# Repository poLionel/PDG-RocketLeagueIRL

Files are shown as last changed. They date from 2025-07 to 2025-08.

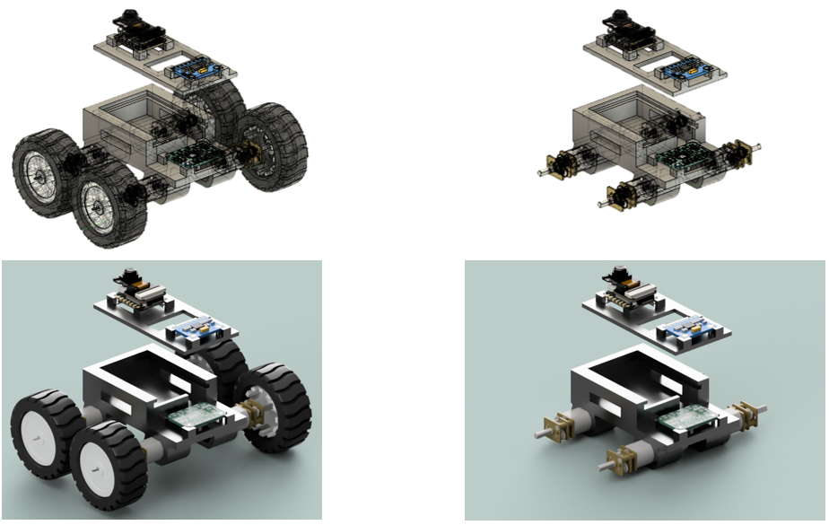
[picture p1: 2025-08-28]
cars/hardware/3d/all_perspectives.png

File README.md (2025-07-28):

# PDG-RocketLeagueIRL

https://polionel.github.io/PDG-RocketLeagueIRL/

Demonstration

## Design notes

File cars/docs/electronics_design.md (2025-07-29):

# Design

Ce document décrit les choix techniques et la justification des composants sélectionnés pour la conception des voitures.  
Le composant central est l’**ESP32-S3 avec caméra intégrée**, qui assure à la fois la gestion des capteurs, la communication et le contrôle moteur.

---

## 1. Composant central : ESP32-S3 + Caméra intégrée
- **Rôle :**  
  - Microcontrôleur principal du véhicule  
  - Gestion des entrées/sorties (moteurs, capteurs)  
  - Traitement de la vidéo embarquée pour détection et streaming
  - Communication avec le serveur (Wi-Fi et Bluetooth)
- **Justification :**  
  - Intègre Wi-Fi et Bluetooth (pas besoin de module externe)  
  - Supporte traitement d'image embarqué (via capteur OV2640)  
  - Gestion de charge batterie Li-Po 3,7 V
- **Référence choisie :** Seeed Studio XIAO ESP32-S3 Sense  
  - Compact, facile à intégrer dans un châssis  
  - Caméra intégrée 
  - Prix compétitif

---

## 2. Moteurs DC
- **Rôle :**  
  - Fournir la propulsion et le contrôle directionnel
- **Justification :**  
  - Simplicité de commande via driver H-bridge  
  - Tension compatible avec la batterie Li-Po 3,7 V  
  - Disponibilité en lots à faible coût
- **Référence :** JYD061217 – JIE YI ELECTRONICS  
  - Couple suffisant pour la taille et le poids prévus du véhicule

---

## 3. Driver moteur DC double canal (Adafruit DRV8833)
- **Rôle :**  
  - Piloter deux moteurs DC en contrôle bidirectionnel  
- **Justification :**  
  - Double pont en H, support jusqu’à 1,2 A par moteur  
  - Compatible avec les tensions des moteurs et l’ESP32  
  - Facilement disponible (Adafruit, Digitec)
- **Avantage :**  
  - Commande simple via GPIO de l’ESP32  
  - Compact et efficace

---

## 4. Accéléromètre 3 axes (MPU-6050)
- **Rôle :**  
  - Mesurer l’orientation, l’inclinaison et les chocs  
  - Améliorer le contrôle dynamique du véhicule
- **Justification :**  
  - Très utilisé dans les projets robotiques  
  - Communication I2C facile à intégrer avec l’ESP32  
  - Faible consommation
- **Référence :** Purecrea MPU-6050

---

## 5. Batterie Li-Po
- **Rôle :**  
  Alimenter l’ensemble du système embarqué : microcontrôleur, moteurs et capteurs.

- **Caractéristiques de la batterie sélectionnée :**  
  - Type : Li-Po  
  - Tension : 3.7 V  
  - Capacité : 1000 mAh  

### Consommation maximale estimée :
| Composant | Courant estimé |
|---|---|
| ESP32-S3 + caméra OV2640 | ~330 mA |
| 4 moteurs DC (50 mA chacun) | ~200 mA |
| Driver moteur DRV8833 (pertes internes) | ~20 mA |
| Accéléromètre 3 axes (MPU-6050 avec DMP) | ~6 mA |
| **Total** | **≈ 556 mA** |

### Calcul autonomie batterie :
Formule :  
**Capacité (mAh) = Courant (mA) × Durée (h)**

- Pour 30 minutes (0.5 h) :  
  `556 mA × 0.5 h = 278 mAh`
- Pour 1 heure :  
  `556 mA × 1 h = 556 mAh`

#### 🔒 Marge de sécurité 30 % incluse :
- 30 min → `278 mAh × 1.3 = 361.4 mAh`
- 1 h → `556 mAh × 1.3 = 722.8 mAh`

### Conclusion :
Avec une batterie de **1000 mAh**, le système peut fonctionner :
- Environ **1h30** en utilisation soutenue
- Avec **30 % de marge**, il couvre confortablement **jusqu'à 1h en pleine charge continue**

---

## 📌 Conclusion
L’architecture repose sur un ESP32-S3 centralisé, relié directement aux moteurs via driver, et aux capteurs via bus I2C.  
Ce choix maximise la compacité, la performance et la facilité de développement tout en restant économique.

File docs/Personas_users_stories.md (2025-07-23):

# Personas

## Joueur qui connaît Rocket League

**Description :**
Passionné du jeu vidéo Rocket League, il connaît déjà les mécaniques, les règles et les stratégies du jeu virtuel. Il recherche une expérience fidèle et compétitive dans le monde réel.

**Buts :**
- Retrouver les sensations et la dynamique du jeu vidéo.
- Tester ses compétences dans un contexte physique.
- S’amuser et relever des défis contre d’autres joueurs expérimentés.

## Joueur qui ne connaît pas Rocket League

**Description :**
Découvre le concept Rocket League pour la première fois. Il aime les jeux ou les activités ludiques, mais n’a pas d’expérience préalable avec le jeu vidéo.

**Buts :**
- Comprendre rapidement les règles et la prise en main.
- S’amuser sans être désavantagé par son manque d’expérience.
- Profiter d’une expérience accessible et intuitive.

## Arbitre

**Description :**
Personne responsable du bon déroulement des matchs, du respect des règles et de la validation des scores. Il peut être membre de l’organisation ou un joueur désigné.

**Buts :**
- Garantir l’équité et la sécurité pendant les parties.
- Gérer les litiges et valider les événements de jeu (buts, fautes).
- Disposer d’outils simples pour surveiller et contrôler la partie.

## Spectateur

**Description :**
Individu qui assiste aux matchs sans y participer directement. Il peut être un proche des joueurs, un fan ou un curieux.

**Buts :**
- Suivre l’action en direct de façon immersive.
- Comprendre facilement le score et les événements du match.
- Profiter d’une expérience divertissante, éventuellement via une application ou un écran.

## Développeur ou contributeur externe

**Description :**
Personne souhaitant contribuer au projet (ajout de fonctionnalités, correction de bugs, documentation). Peut être membre de l’équipe ou externe.

**Buts :**
- Comprendre rapidement l’architecture et les conventions du projet.
- Pouvoir tester et déployer facilement ses modifications.
- Participer à une communauté ouverte et bien documentée.

# User Stories

## Joueur qui connaît Rocket League

- En tant que joueur expérimenté, je veux retrouver les mêmes sensations de contrôle qu’en jeu vidéo pour m’adapter rapidement.
- En tant que joueur expérimenté, je veux pouvoir utiliser des stratégies avancées pour prendre l’avantage sur mes adversaires.
- En tant que joueur expérimenté, je veux que le système gère les collisions.
- En tant que joueur expérimenté, je veux que le système gère les boosts.
- En tant que joueur expérimenté, je veux accéder à des statistiques détaillées de mes parties pour analyser mes performances.
- En tant que joueur expérimenté, je veux pouvoir personnaliser les contrôles de l’application mobile selon mes préférences.

## Joueur qui ne connaît pas Rocket League

- En tant que nouveau joueur, je veux un tutoriel simple pour comprendre rapidement les règles du jeu.
- En tant que nouveau joueur, je veux que l’interface soit intuitive afin de prendre en main la voiture sans difficulté.
- En tant que nouveau joueur, je veux pouvoir jouer sans être désavantagé face à des joueurs expérimentés.
- En tant que nouveau joueur, je veux pouvoir rejoindre une partie facilement.

## Arbitre

- En tant qu’arbitre, je veux pouvoir valider ou annuler un but depuis une interface dédiée.
- En tant qu’arbitre, je veux pouvoir mettre en pause ou arrêter la partie à tout moment.
- En tant qu’arbitre, je veux accéder à un historique des événements pour résoudre les litiges.
- En tant qu’arbitre, je veux pouvoir modifier le score manuellement si nécessaire.

## Spectateur

- En tant que spectateur, je veux suivre le match en direct via un flux vidéo pour ne rien manquer de l’action.
- En tant que spectateur, je veux voir le score et le temps restant affichés clairement.
- En tant que spectateur, je veux pouvoir choisir la vue de la voiture.
- En tant que spectateur, je veux recevoir des notifications lors des moments clés (buts, boosts, collisions).

## Développeur ou contributeur externe

- En tant que développeur, je veux accéder à une documentation claire pour comprendre rapidement le projet.
- En tant que développeur, je veux pouvoir lancer un environnement de test local.
- En tant que développeur, je veux que le code soit bien structuré et commenté pour faciliter mes contributions.
- En tant que développeur, je veux soumettre des modifications via des pull requests et recevoir des retours.
- En tant que développeur, je veux que les tests automatisés valident mes changements avant intégration.

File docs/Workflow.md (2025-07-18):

 # 1. Architecture du repo

```arduino
rocket-league-physique/
├── server/        # ???
├── cars/          # ???
├── mobile/        # appli .NET MAUI
├── infra/         # docker-compose, scripts Ansible/Terraform
└── docs/          # schémas, spécs, README, wiki…
```

# 2. Système de branches (Git-flow)

develop

    - Branche d’intégration continue.
    - On y merge toutes les feature/* et bugfix/*.

feature/xxx & bugfix/yyy

    - Branches filles de develop (git checkout -b feature/123-nouvelle-cam).
    - PR → merge → CI runs.

release/vX.Y.Z

    - Créée depuis develop quand on est prêt pour une version.
    - Stabilisation (QA, tests E2E) sans intégrer de nouvelles features.
    - Puis merge → main + tag vX.Y.Z → déploiement.
    - Merge aussi vers develop pour récupérer correctifs.

main

    - Branche de production, jamais de merges directs de features.
    - Chaque tag vX.Y.Z sur main déclenche le CD.

hotfix/vX.Y.Z

    - Branche crée depuis main pour corriger urgemment un bug.
    - Corrections en branches filles (hotfix/vX.Y.Z-fix…) → PR → merge dans hotfix/vX.Y.Z.
    - Merge → main + tag → déploiement immédiat.
    - Merge → develop pour propager la correction.

# 3. Tags Git & Releases
- Format sémantique : vMAJEUR.MINOR.PATCH (ex. v1.0.0, v1.2.2)
- Création anotée :

```bash
git tag -a v1.1.2 -m "Hotfix v1.1.2 - Crash x fix"
git push origin v.1.1.2
```

- Usage
    - Reste figé sur le commit de release
    - Déclencheur CD (dans cd.yaml)

- Github Releases : associez notes de version et artefacts (Docker, firmware,...)

# 4. Pipelines Github Actions
## 1) .github/workflows/ci.yaml
    - Déchencheurs : push & pull_request sur develop, feature/*, bugfix/*
    - Jobs (parallèles) :
        - Test AppMobile (dotnet test)
        - Test Server
        - Test Firmware
    - Objectif : feedback rapide, qualité du code

## 2) .github/workflows/e2e.yaml (todo : à voir si besoin)

## 3) .github/workflows/cd.yaml
    - Déclencheur : push de tags v*.*.*
    - Job :
        - A voir mais build & push docker images, générer binaire, ...

# 5. Outils & environnements
    - Issue tracker : Github Issues + Project (kanban), templates, labels(bug, feature, etc)
    - Docs : dossier docs/
    - autres ?

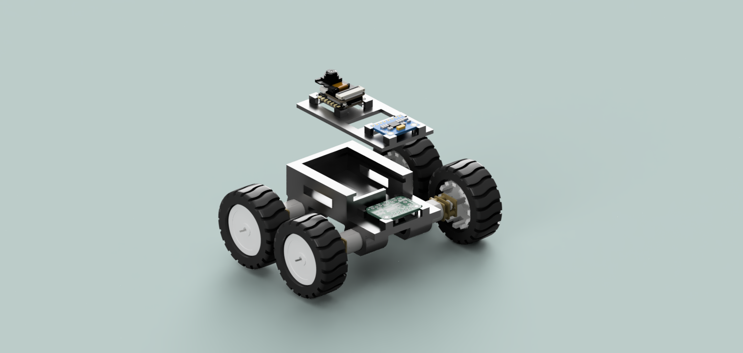
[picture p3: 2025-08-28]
cars/hardware/3d/car_full_with_wheels.PNG

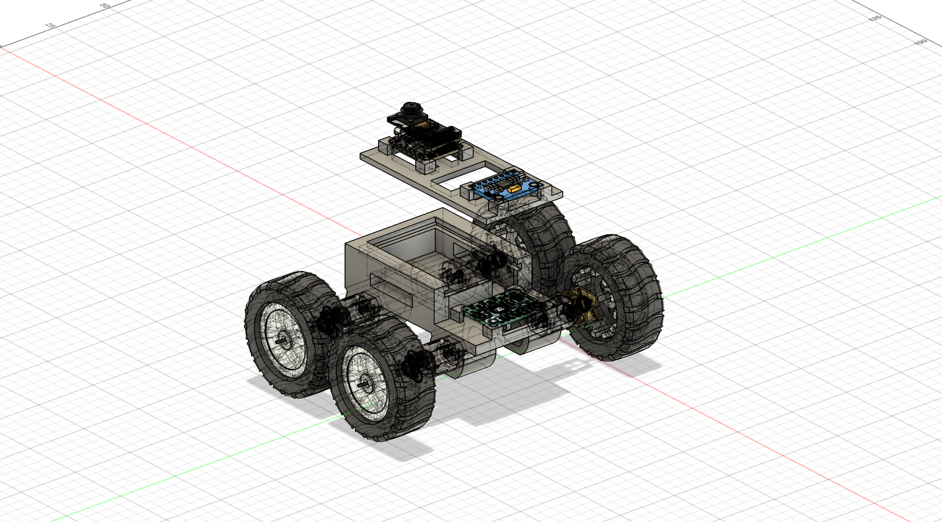
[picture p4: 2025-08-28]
cars/hardware/3d/car_chassis_v3.png

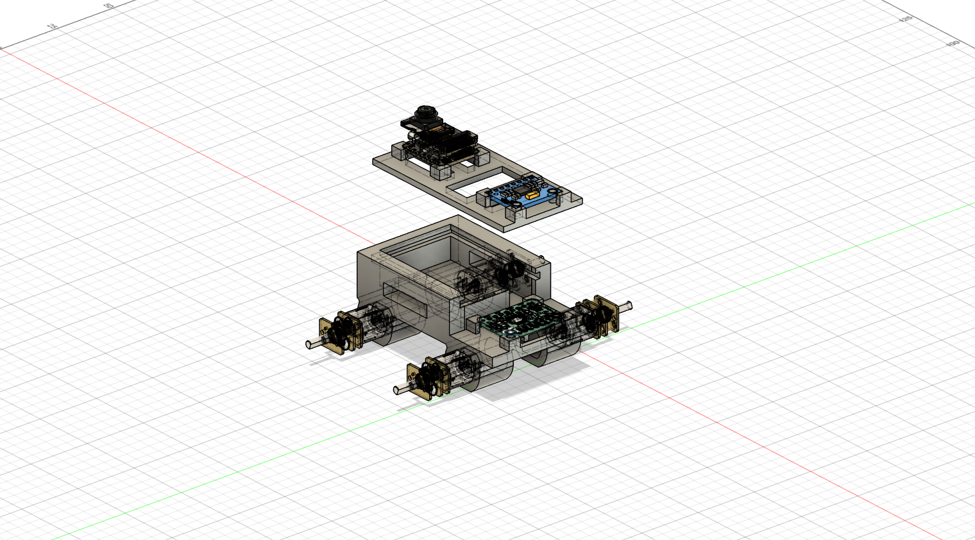
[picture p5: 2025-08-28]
cars/hardware/3d/car_chassis_v4.png

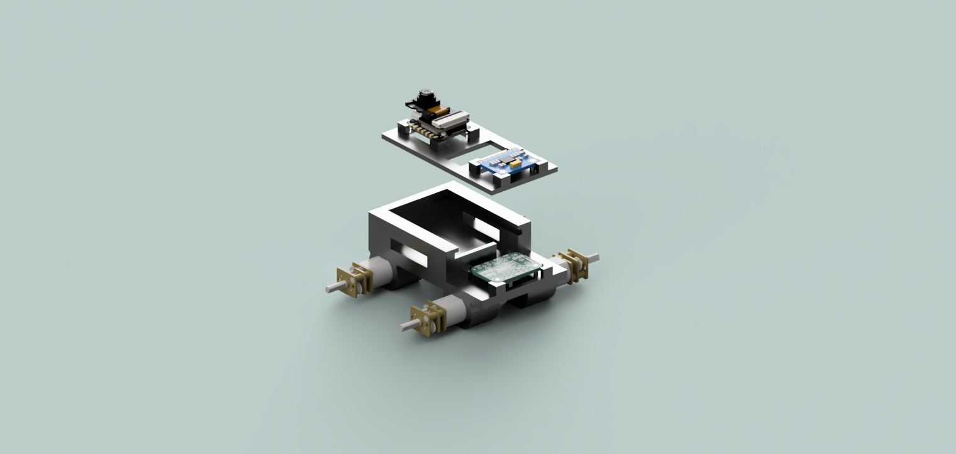
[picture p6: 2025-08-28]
cars/hardware/3d/car_full_without_wheels.png

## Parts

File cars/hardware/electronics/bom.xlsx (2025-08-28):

Composant | Quantité | Caractéristiques | Nom Fournisseur | Référence Fournisseur | Prix unitaire | Total
Moteur GA12-N20 DC 3V | 4 | Tension nominale : 3V Courant nominale : 70mA Couple nomiale : 2kg*cm Vitesse à vide : 100 RPM | Digikey | https://www.amazon.fr/-/en/gp/product/B0CJY5QH7W?ref=ppx_pt2_dt_b_prod_image&th=1 | 1.88 | 7.52
Module ESP32 + caméra intégré | 1 | Type Processeur : ESP32-S3 Capteur intégré : OV2640 Batterie : compatible 3.7V Li‑Ion Wi-Fi : Wi‑Fi 802.11 b/g/n Bluetooth : 5 (BLE) Consommation maximale: (CPU+WiFi+BLE)~240mA + (Cam.OV2640)~60mA + (ChargeurLiPo)~20-30mA =230-330mA | Digitec | Seeed Studio XIAO ESP32 S3 Sense avec caméra - acheter sur Digitec (https://www.digitec.ch/fr/s1/product/seeed-studio-xiao-esp32-s3-sense-avec-camera-carte-de-developpement-kit-35506126) | 30.9 | 30.9
Module driver moteur DC double canal Adafruit DRV8833 | 1 | Type : Double pont en H Tension moteur : 2.7 V à 10.8 V Courant max : 1.2 A continu Entrée logique : 3.3 V / 5 V Contrôle : PWM, sens, ... Nombre de canaux : 2 consommation : 20mA (pertes) | Digitec | Adafruit DRV8833 Tableau d'affichage pour les conducteurs de moteurs pas à pas - Digitec (https://www.digitec.ch/fr/s1/product/adafruit-drv8833-tableau-daffichage-pour-les-conducteurs-de-moteurs-pas-a-pas-diode-5998725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) | 12.9 | 12.9
Module accelérometre 3 axes Purecrea MPU-6050 | 1 | Alimentation : 3,3 V à 5 V Communication : I2C Mesure : ± 2 g, ± 4 g, ± 8 g, ± 16 g Consommation : 5,5 mA | Digitec | Purecrea MPU-6050 3-axis accelerometer with gyroscope - buy at Digitec (https://www.digitec.ch/en/s1/product/purecrea-mpu-6050-3-axis-accelerometer-with-gyroscope-development-boards-kits-36359715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) | 12.9 | 12.9
Batterie | 1 | Li-Po 3.7 V 1000 mAh | Digitec | Akyga LP803040 Akkupack x Spezial-Akku LiPo 3.7 V 1000 mAh - Digitec (https://www.digitec.ch/fr/s1/product/akyga-lp803040-akkupack-x-spezial-akku-lipo-37-v-1000-mah-370-v-1000-mah-batterie-rc-56400957) | 7.9 | 7.9
 |  |  |  |  | Total | 72.12

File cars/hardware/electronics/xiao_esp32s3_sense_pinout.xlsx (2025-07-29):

Name | No. | Type | Power Domain | Function
LNA_IN | 1 | I/O | — | RF input and output
VDD3P3 | 2 | PA | — | Analog Power
VDD3P3 | 3 | PA | — | Analog Power
CHIP_PU | 4 | I | VDD3P3_RTC | High level: chip enable; Low: chip off; Note that the CHIP_PU pin cannot be left floating.
GPIO0 | 5 | I/O/T | VDD3P3_RTC | RTC_GPIO0 | GPIO0 |  |  |  |  |  | BOOT
GPIO1 | 6 | I/O/T | VDD3P3_RTC | RTC_GPIO1 | GPIO1 | TOUCH1 | ADC1_CH0 |  |  |  | D0 | A0 | GPIO1 | TOUCH1
GPIO2 | 7 | I/O/T | VDD3P3_RTC | RTC_GPIO2 | GPIO2 | TOUCH2 | ADC1_CH1 |  |  |  | D1 | A1 | GPIO2 | TOUCH2
GPIO3 | 8 | I/O/T | VDD3P3_RTC | RTC_GPIO3 | GPIO3 | TOUCH3 | ADC1_CH2 |  |  |  | D2 | A2 | GPIO3 | TOUCH3
GPIO4 | 9 | I/O/T | VDD3P3_RTC | RTC_GPIO4 | GPIO4 | TOUCH4 | ADC1_CH3 |  |  |  | D3 | A3 | GPIO4 | TOUCH4
GPIO5 | 10 | I/O/T | VDD3P3_RTC | RTC_GPIO5 | GPIO5 | TOUCH5 | ADC1_CH4 |  |  |  | D4 | A4 | GPIO5 | TOUCH5 | SDA
GPIO6 | 11 | I/O/T | VDD3P3_RTC | RTC_GPIO6 | GPIO6 | TOUCH6 | ADC1_CH5 |  |  |  | D5 | A5 | GPIO6 | TOUCH6 | SCL
GPIO7 | 12 | I/O/T | VDD3P3_RTC | RTC_GPIO7 | GPIO7 | TOUCH7 | ADC1_CH6 |  |  |  | D8 | A8 | GPIO7 | TOUCH7 | SCK
GPIO8 | 13 | I/O/T | VDD3P3_RTC | RTC_GPIO8 | GPIO8 | TOUCH8 | ADC1_CH7 | SUBSPICS1 |  |  | D9 | A9 | GPIO8 | TOUCH8 | MISO
GPIO9 | 14 | I/O/T | VDD3P3_RTC | RTC_GPIO9 | GPIO9 | TOUCH9 | ADC1_CH8 | SUBSPIHD | FSPIHD |  | D10 | A10 | GPIO9 | TOUCH9 | MOSI
GPIO10 | 15 | I/O/T | VDD3P3_RTC | RTC_GPIO10 | GPIO10 | TOUCH10 | ADC1_CH9 | FSPIIO4 | SUBSPICS0 | FSPICS0 | XMCLK |  | GPIO10
GPIO11 | 16 | I/O/T | VDD3P3_RTC | RTC_GPIO11 | GPIO11 | TOUCH11 | ADC2_CH0 | FSPIIO5 | SUBSPID | FSPID | Y8 |  | GPIO11
GPIO12 | 17 | I/O/T | VDD3P3_RTC | RTC_GPIO12 | GPIO12 | TOUCH12 | ADC2_CH1 | FSPIIO6 | SUBSPICLK | FSPICLK | Y7 |  | GPIO12
GPIO13 | 18 | I/O/T | VDD3P3_RTC | RTC_GPIO13 | GPIO13 | TOUCH13 | ADC2_CH2 | FSPIIO7 | SUBSPIQ | FSPIQ | PCLK |  | GPIO13
GPIO14 | 19 | I/O/T | VDD3P3_RTC | RTC_GPIO14 | GPIO14 | TOUCH14 | ADC2_CH3 | FSPIDQS | SUBSPIWP | FSPIWP | Y6 |  | GPIO14
VDD3P3_RTC | 20 | PA | — | Analog Power
XTAL_32K_P | 21 | I/O/T | VDD3P3_RTC | RTC_GPIO15 | GPIO15 | U0RTS | ADC2_CH4 | XTAL_32K_P |  |  | Y2 |  | GPIO15
XTAL_32K_N | 22 | I/O/T | VDD3P3_RTC | RTC_GPIO16 | GPIO16 | U0CTS | ADC2_CH5 | XTAL_32K_N |  |  | Y5 |  | GPIO16
GPIO17 | 23 | I/O/T | VDD3P3_RTC | RTC_GPIO17 | GPIO17 | U1TXD | ADC2_CH6 |  |  |  | Y3 |  | GPIO17
GPIO18 | 24 | I/O/T | VDD3P3_RTC | RTC_GPIO18 | GPIO18 | U1RXD | ADC2_CH7 | CLK_OUT3 |  |  | Y4 |  | GPIO18
GPIO19 | 25 | I/O/T | VDD3P3_RTC | RTC_GPIO19 | GPIO19 | U1RTS | ADC2_CH8 | CLK_OUT2 | USB_D- |  | D-
GPIO20 | 26 | I/O/T | VDD3P3_RTC | RTC_GPIO20 | GPIO20 | U1CTS | ADC2_CH9 | CLK_OUT1 | USB_D+ |  | D+
GPIO21 | 27 | I/O/T | VDD3P3_RTC | RTC_GPIO21 | GPIO21 |  |  |  |  |  | User_LED |  | GPIO21
SPICS1 | 28 | I/O/T | VDD_SPI | SPICS1 | GPIO26
VDD_SPI | 29 | PD | — | 1.8 V or VDD3P3_RTC power output
SPIHD | 30 | I/O/T | VDD_SPI | SPIHD | GPIO27
SPIWP | 31 | I/O/T | VDD_SPI | SPIWP | GPIO28
SPICS0 | 32 | I/O/T | VDD_SPI | SPICS0 | GPIO29
SPICLK | 33 | I/O/T | VDD_SPI | SPICLK | GPIO30
SPIQ | 34 | I/O/T | VDD_SPI | SPIQ | GPIO31
SPID | 35 | I/O/T | VDD_SPI | SPID | GPIO32
SPICLK_N | 36 | I/O/T | VDD_SPI | SPICLK_N_DIFF | GPIO48 | SUBSPICLK_N_DIFF |  |  |  |  | Y9 |  | GPIO48
SPICLK_P | 37 | I/O/T | VDD_SPI | SPICLK_P_DIFF | GPIO47 | SUBSPICLK_P_DIFF |  |  |  |  | HREF |  | GPIO47
GPIO33 | 38 | I/O/T | VDD3P3_CPU / VDD_SPI | SPIIO4 | GPIO33 | FSPIHD | SUBSPIHD
GPIO34 | 39 | I/O/T | VDD3P3_CPU / VDD_SPI | SPIIO5 | GPIO34 | FSPICS0 | SUBSPICS0
GPIO35 | 40 | I/O/T | VDD3P3_CPU / VDD_SPI | SPIIO6 | GPIO35 | FSPID | SUBSPID
GPIO36 | 41 | I/O/T | VDD3P3_CPU / VDD_SPI | SPIIO7 | GPIO36 | FSPICLK | SUBSPICLK
GPIO37 | 42 | I/O/T | VDD3P3_CPU / VDD_SPI | SPIDQS | GPIO37 | FSPIQ | SUBSPIQ
GPIO38 | 43 | I/O/T | VDD3P3_CPU | GPIO38 | FSPIWP | SUBSPIWP |  |  |  |  | VSYNC |  | GPIO38
MTCK | 44 | I/O/T | VDD3P3_CPU | MTCK | GPIO39 | CLK_OUT3 | SUBSPICS1 |  |  |  | Cam_SCL |  | GPIO39 | MTCK
MTDO | 45 | I/O/T | VDD3P3_CPU | MTDO | GPIO40 | CLK_OUT2 |  |  |  |  | Cam_SDA |  | GPIO40 | MTDO
VDD3P3_CPU | 46 | PD | — | CPU IO power input
MTDI | 47 | I/O/T | VDD3P3_CPU | MTDI | GPIO41 | CLK_OUT1 |  |  |  |  | D12 | PDM_DATA | GPIO41 | MTDI
MTMS | 48 | I/O/T | VDD3P3_CPU | MTMS | GPIO42 |  |  |  |  |  | D11 | PDM_CLK | GPIO42 | MTMS
U0TXD | 49 | I/O/T | VDD3P3_CPU | U0TXD | GPIO43 | CLK_OUT1 |  |  |  |  | D6 | TX | GPIO43
U0RXD | 50 | I/O/T | VDD3P3_CPU | U0RXD | GPIO44 | CLK_OUT2 |  |  |  |  | D7 | RX | GPIO44
GPIO45 | 51 | I/O/T | VDD3P3_CPU | GPIO45
GPIO46 | 52 | I/O/T | VDD3P3_CPU | GPIO46
XTAL_N | 53 | — | — | External master crystal output
XTAL_P | 54 | — | — | External master crystal input
VDDA1 | 55 | PA | — | Analog Power
VDDA2 | 56 | PA | — | Analog Power
GND | 57 | G | — | GND
 |  |  |  |  |  |  |  |  |  | BOOT
 |  |  |  |  |  |  |  |  |  | JTAG
 |  |  |  |  |  |  |  |  |  | Camera
 |  |  |  |  |  |  |  |  |  | TOUCH
 |  |  |  |  |  |  |  |  |  | SPI
 |  |  |  |  |  |  |  |  |  | ALL PWM
 |  |  |  |  |  |  |  |  |  | USB
 |  |  |  |  |  |  |  |  |  | Analog
 |  |  |  |  |  |  |  |  |  | IIC
 |  |  |  |  |  |  |  |  |  | Digital
 |  |  |  |  |  |  |  |  |  | GPIO
 |  |  |  |  |  |  |  |  |  | MIC
 |  |  |  |  |  |  |  |  |  | UART
 |  |  |  |  | BPI-PicoW-S3 外设GPIO管脚分配
 |  |  |  |  | 外设接口 | 信号 | 管脚
 |  |  |  |  | ADC | ADC1_CH0~9 | GPIO 1~10
 |  |  |  |  |  | ADC2_CH0~9 | GPIO 11~20
 |  |  |  |  | 触摸传感器 | TOUCH1~14 | GPIO 1~14
 |  |  |  |  | JTAG | MTCK | GPIO 39
 |  |  |  |  |  | MTDO | GPIO 40
 |  |  |  |  |  | MTDI | GPIO 41
 |  |  |  |  |  | MTMS | GPIO 42
 |  |  |  |  | UART | 默认分配管脚，可重定义为任意GPIO
 |  |  |  |  |  | U0RXD_in | GPIO 44
 |  |  |  |  |  | U0CTS_in | GPIO 16
 |  |  |  |  |  | U0DSR_in | 任意GPIO
 |  |  |  |  |  | U0TXD_out | GPIO43
 |  |  |  |  |  | U0RTS_out | GPIO 15
 |  |  |  |  |  | U0DTR_out | 任意GPIO
 |  |  |  |  |  | U1RXD_in | GPIO 18
 |  |  |  |  |  | U1CTS_in | GPIO 20
 |  |  |  |  |  | U1DSR_in | 任意GPIO
 |  |  |  |  |  | U1TXD_out | GPIO 17
 |  |  |  |  |  | U1RTS_out | GPIO 19
 |  |  |  |  |  | U1DTR_out | 任意GPIO
 |  |  |  |  |  | U2 | 任意GPIO
 |  |  |  |  | I2C | 任意GPIO
 |  |  |  |  | PWM | 任意GPIO
 |  |  |  |  | I2S | 任意GPIO
 |  |  |  |  | LCD | 任意GPIO
 |  |  |  |  | CAMERA | 任意GPIO
 |  |  |  |  | RMT | 任意GPIO
 |  |  |  |  | SPI0/1 | 已用于FLASH与PSRAM
 |  |  |  |  | SPI2/3 | 任意GPIO
 |  |  |  |  | 脉冲计数器 | 任意GPIO
 |  |  |  |  | USB OTG | D- | GPIO 19（内部 PHY）
 |  |  |  |  |  | D+ | GPIO 20（内部 PHY）
 |  |  |  |  |  | VP | GPIO 42（外部 PHY）
 |  |  |  |  |  | VM | GPIO 41（外部 PHY）
 |  |  |  |  |  | RCV | GPIO21（外部 PHY）
 |  |  |  |  |  | OEN | GPIO 40（外部 PHY）
 |  |  |  |  |  | VPO | GPIO 39（外部 PHY）
 |  |  |  |  |  | VMO | GPIO38（外部 PHY）
 |  |  |  |  | USB Serial/JTAG | D- | GPIO 19（内部 PHY）
 |  |  |  |  |  | D+ | GPIO 20（内部 PHY）
 |  |  |  |  |  | VP | GPIO 42（外部 PHY）
 |  |  |  |  |  | VM | GPIO 41（外部 PHY）
 |  |  |  |  |  | OEN | GPIO 40（外部 PHY）
 |  |  |  |  |  | VPO | GPIO 39（外部 PHY）
 |  |  |  |  |  | VMO | GPIO38（外部 PHY）
 |  |  |  |  | SD/MMC | 任意GPIO
 |  |  |  |  | MCPWM | 任意GPIO
 |  |  |  |  | TWAI | 任意GPIO
 |  |  |  |  | 彩色LED | GPIO 48
 |  |  |  |  | 单色LED | GPIO 46

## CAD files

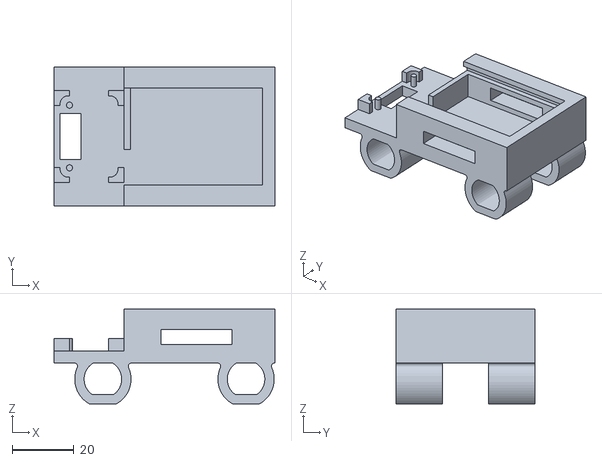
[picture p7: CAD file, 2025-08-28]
cars/hardware/3d/car_chassis.stl
71.8 x 45.0 x 30.7

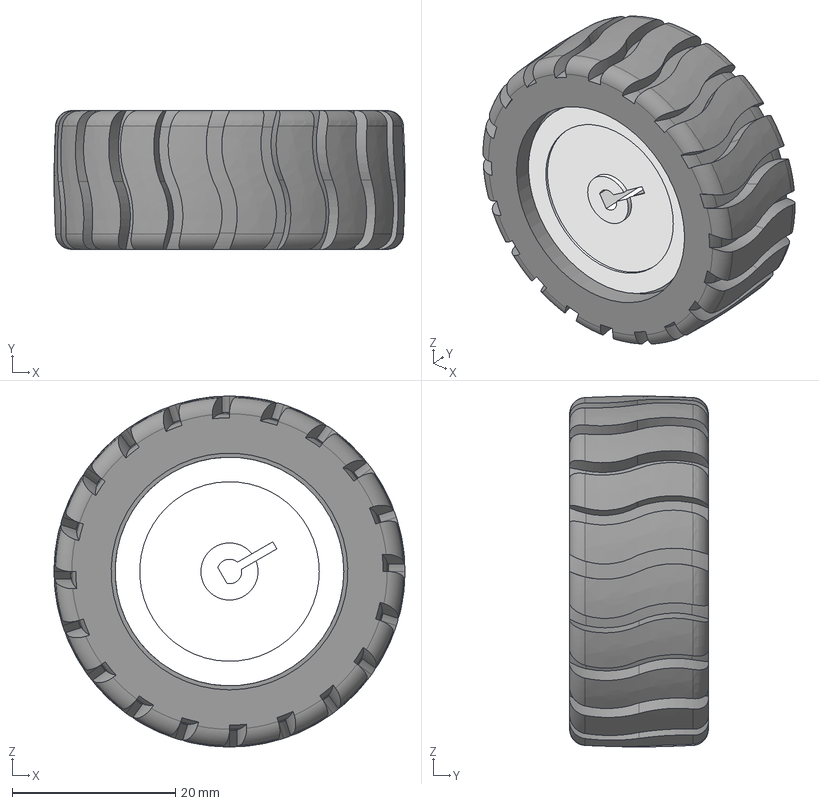
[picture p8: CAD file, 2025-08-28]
cars/hardware/3d/n20_wheel.step
43.0 x 17.0 x 43.0 mm

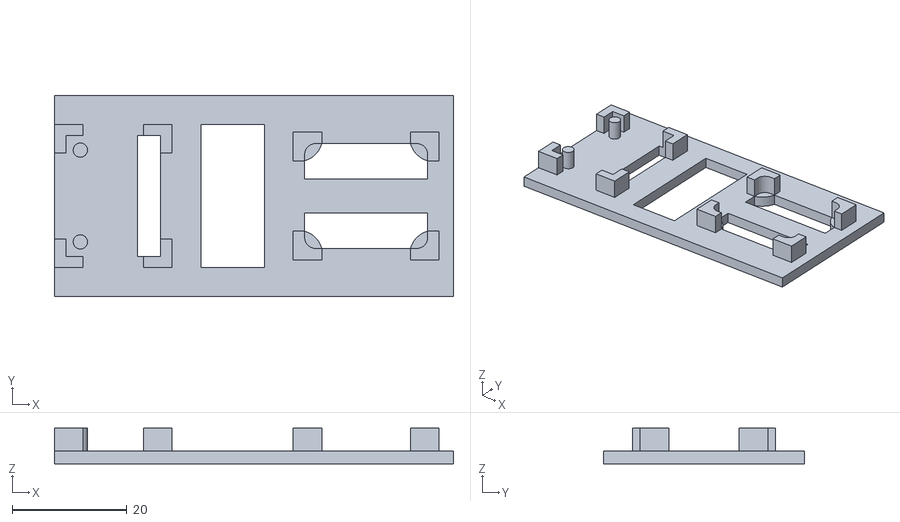
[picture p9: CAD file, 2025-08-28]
cars/hardware/3d/car_base.stl
69.5 x 35.0 x 6.25

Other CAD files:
cars/hardware/3d/car_wheel.stl

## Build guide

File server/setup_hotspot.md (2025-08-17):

# Point d’accès Wi‑Fi Raspberry Pi (hostapd + dnsmasq) — Guide « copier‑coller »

Configure un Pi en point d’accès 2,4 GHz WPA2 sur `wlan0`, avec Internet via `eth0` (Ethernet).

> Modèle testé pour Raspberry Pi OS (Bullseye/Bookworm) avec systemd.

---

## Prérequis (à faire une fois)

Quelques paquets et réglages système nécessaires avant d’activer le hotspot.

```bash
# Met à jour l’index des paquets et installe hostapd/dnsmasq, outils Wi‑Fi et firmwares
sudo apt-get update
sudo apt-get install -y hostapd dnsmasq wireless-tools iw iptables-persistent   firmware-brcm80211 firmware-misc-nonfree

# Démasque hostapd (si masqué par défaut) et arrête hostapd/dnsmasq le temps de la config
sudo systemctl unmask hostapd
sudo systemctl stop hostapd dnsmasq 2>/dev/null || true

# Définit le domaine réglementaire Wi‑Fi (remplacez CH par votre pays: FR/BE/CH/CA…)
sudo iw reg set CH

# Évite des résolutions d’hôte lentes en ajoutant l’IP du Pi à /etc/hosts
echo "$(hostname -I | awk '{print $1}') $(hostname)" | sudo tee -a /etc/hosts >/dev/null
```

---

## Hotspot sur `wlan0`, Internet via `eth0`

### Donner une IP statique à `wlan0` (et désactiver le mode client)

Astuce: la commande sed supprime tout bloc existant pour `wlan0` dans `/etc/dhcpcd.conf`. Sauvegardez si nécessaire.

```bash
# Nettoie d’anciennes sections wlan0 dans dhcpcd.conf
sudo sed -i '/^interface wlan0/,$d' /etc/dhcpcd.conf

# Ajoute une IPv4 statique et coupe wpa_supplicant côté client sur wlan0
sudo tee -a /etc/dhcpcd.conf >/dev/null <<'EOF'
# Point d’accès: IP statique du Raspberry Pi sur le réseau Wi‑Fi privé
interface wlan0
  static ip_address=10.42.0.1/24
  # Empêche wpa_supplicant de gérer wlan0 (le Pi ne se connecte pas en client)
  nohook wpa_supplicant
EOF

# Applique la nouvelle configuration IP
sudo systemctl restart dhcpcd
```

### Configuration `hostapd` : Choisissez entre WPA2-PSK (sécurisé) ou réseau ouvert

Vous pouvez configurer le point d’accès en mode sécurisé (WPA2-PSK) ou ouvert (sans chiffrement).  
**Le mode ouvert est déconseillé en production car il n’y a aucune sécurité.**

#### Option 1 : WPA2-PSK (recommandé)

Modifiez `ssid`, `wpa_passphrase`, `country_code` et `channel` selon vos besoins.

```bash
sudo mkdir -p /etc/hostapd

# Fichier de configuration du point d’accès sécurisé
sudo tee /etc/hostapd/hostapd.conf >/dev/null <<'EOF'
# AP 2.4 GHz sur wlan0
interface=wlan0
driver=nl80211

# Identité du réseau (SSID) et pays (réglementation radio)
ssid=RL-Hotspot            # Nom du Wi‑Fi
country_code=CH            # Adaptez à votre pays (p.ex. FR, BE, CA, CH)

# Bande 2,4 GHz (802.11g/n) et canal
hw_mode=g
channel=1                  # Choisissez un canal libre (1/6/11 en général)

# Qualité de service et 802.11n
wmm_enabled=1
ieee80211n=1
ht_capab=[SHORT-GI-20]

# Sécurité WPA2‑PSK (AES)
auth_algs=1
wpa=2
wpa_passphrase=rocketleague  # Changez ce mot de passe
wpa_key_mgmt=WPA-PSK
rsn_pairwise=CCMP
EOF

# Pointeur du service hostapd vers ce fichier de configuration
echo 'DAEMON_CONF="/etc/hostapd/hostapd.conf"' | sudo tee /etc/default/hostapd
```

#### Option 2 : Réseau ouvert (non sécurisé)

Modifiez `ssid`, `country_code` et `channel` selon vos besoins.

```bash
sudo mkdir -p /etc/hostapd

# Fichier de configuration du point d’accès ouvert (aucune sécurité !)
sudo tee /etc/hostapd/hostapd.conf >/dev/null <<'EOF'
# AP 2.4 GHz sur wlan0
interface=wlan0
driver=nl80211

# Identité du réseau (SSID) et pays (réglementation radio)
ssid=RL-Hotspot            # Nom du Wi‑Fi
country_code=CH            # Adaptez à votre pays (p.ex. FR, BE, CA, CH)

# Bande 2,4 GHz (802.11g/n) et canal
hw_mode=g
channel=1                  # Choisissez un canal libre (1/6/11 en général)

# Qualité de service et 802.11n
wmm_enabled=1
ieee80211n=1
ht_capab=[SHORT-GI-20]

# Réseau ouvert (sans chiffrement). Attention: non sécurisé.
auth_algs=1
EOF

# Pointeur du service hostapd vers ce fichier de configuration
echo 'DAEMON_CONF="/etc/hostapd/hostapd.conf"' | sudo tee /etc/default/hostapd
```

### Configuration `dnsmasq` (DHCP/DNS pour les clients)

Distribue des adresses IP aux clients du Wi‑Fi et relaie le DNS.

```bash
sudo mkdir -p /etc/dnsmasq.d

# Pool DHCP sur le sous-réseau 10.42.0.0/24, DNS publics Cloudflare/Google
sudo tee /etc/dnsmasq.d/hotspot.conf >/dev/null <<'EOF'
# Interface du point d’accès
interface=wlan0
bind-interfaces

# Hygiène DNS
domain-needed
bogus-priv

# Plage DHCP (baux de 12 h) et serveurs DNS
dhcp-range=10.42.0.50,10.42.0.150,255.255.255.0,12h
dhcp-option=6,1.1.1.1,8.8.8.8
EOF
```

### Activer le routage IPv4 + NAT vers l’interface Ethernet

Active le forwarding IP et fait du masquerading (NAT) vers `eth0` pour donner Internet aux clients.

```bash
# Active le routage IPv4 de manière persistante
echo 'net.ipv4.ip_forward=1' | sudo tee /etc/sysctl.d/99-ipforward.conf
sudo sysctl -p /etc/sysctl.d/99-ipforward.conf

# Ajoute (si absent) la règle NAT de sortie vers eth0 puis sauvegarde
sudo iptables -t nat -C POSTROUTING -o eth0 -j MASQUERADE 2>/dev/null || sudo iptables -t nat -A POSTROUTING -o eth0 -j MASQUERADE
sudo netfilter-persistent save
```

### Démarrer les services

Désactive `wpa_supplicant` sur `wlan0` (mode client) et lance `hostapd` + `dnsmasq`.

```bash
# S’assure que wpa_supplicant ne gère pas wlan0
sudo systemctl stop wpa_supplicant@wlan0.service 2>/dev/null || true
sudo systemctl stop wpa_supplicant.service 2>/dev/null || true

# Active et démarre les services du point d’accès et du DHCP/DNS
sudo systemctl enable --now hostapd
sudo systemctl enable --now dnsmasq
```

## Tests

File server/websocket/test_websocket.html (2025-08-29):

# Rocket League IRL WebSocket Test Interface

## 📱 Connection Status

Workflow: Connect → Scan Phase → Control Phase → Send Commands

Disconnected

🔗 Connect ❌ Disconnect

## 🚗 Car Controls

🔄 Refresh Cars 🆓 Get Free Cars 📊 Get Phase Status

## 🔍 Bluetooth Management

Manage Bluetooth discovery and connections:

🔍 Switch to Scan Phase 🎮 Switch to Control Phase 📡 Get Bluetooth Status

🔎 Start BLE Scan ⏹️ Stop BLE Scan

#### Bluetooth Status

Click "Get Bluetooth Status" to check device status

#### 🔗 Pair Device

Device Address: Device Name: 🔗 Pair Device

## 🔧 BLE Car Commands

Send commands directly to cars via Bluetooth Low Energy:

Car ID: Command: Message: X (Steering): 📡 Send Command

#### 📶 WiFi Credentials

SSID: Password: 📶 Set WiFi on All Cars

#### Quick Commands:

🏓 Ping All Cars 📊 Request Status 🧪 Test Message ⬆️ All Forward ⏹️ All Stop

#### Movement Test Patterns:

🔄 Circular Movement Test ∞ Figure-8 Test 🎯 Precision Steering Test 🛑 Emergency Stop All

#### Phase Management:

🔍 Scan Phase 🎮 Control Phase 📊 Phase Status

## 🎮 Controls Help

#### Mouse Controls:

- Forward/Backward/Stop: Use the direction buttons
- Steering: Use the slider or steering buttons
- Boost: Toggle boost on/off while moving
- Car Selection: Select a car to control it exclusively

#### Keyboard Controls:

- W / ↑: Move forward
- S / ↓: Move backward
- A / ←: Steer left (incremental)
- D / →: Steer right (incremental)
- Space / Esc: Emergency stop
- Shift: Activate boost

#### Movement Tests:

- Circular Movement: Tests turning in a circle
- Figure-8: Tests complex steering patterns
- Precision Steering: Tests all steering angles
- Emergency Stop: Immediately stops all cars

Note: Select "Keyboard Control" on a car to enable keyboard controls for that specific car.

## Messages

Clear Messages

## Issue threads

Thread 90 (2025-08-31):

Small improvements and missing feature

UBehrmann, 2025-08-31:
- impove game flow
- add missing routes

Closed 2025-09-04.

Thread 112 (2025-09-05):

Fix multiple client management in server video stream

Xenogix, 2025-09-05:
Currently, the video feed works great when one client is connected to it. The client is implemented under "mobileApp" and the server under "server". What we need, is to modify the server video feed management so it can provide properly the same feed to multiple users at the same time as well as multiple feeds to multiple clients if it does not work alread.

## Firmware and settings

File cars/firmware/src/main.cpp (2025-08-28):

//----------------------------------------------------------------------------------
// INCLUDES
#include <core.h>
#include "car_pins.h"
#include "car_defines.h"



//----------------------------------------------------------------------------------
// COMPOSANTS
battery_component battery_comp{
  "LP803040 LiPo",
  3.7f,
  3.3f,
  4.2f,
  1000.0f
};
motor_component motor_comp{
  "Micro-moteur N20",
  3.0f,
  0.2f,
  100.0f
};
camera_component camera_comp{
  "OV2640 Camera"
};
//----------------------------------------------------------------------------------
// OBJETS GLOBAUX
ble_provisioner             ble_prov;
wifi_provisioner            wifi_prov;
////////////////////////////////////////////////
motor_controller            motor_ctrl({
  {
      GPIO_MOT_A_DIR, GPIO_MOT_A_DIR_PWM, 
      GPIO_MOT_B_DIR, GPIO_MOT_B_DIR_PWM, 
      GPIO_MOT_SLP
  }, 
  {
      motor_decay_mode::fast
  },
  motor_comp
});
////////////////////////////////////////////////
battery_controller          battery_ctrl({
  {
      GPIO_BAT_SENSE
  }, 
  {
      100000, 100000, 8, 
  },
  battery_comp
});
////////////////////////////////////////////////
camera_controller           camera_ctrl({
  {   
      GPIO_CAM_PWDN, GPIO_CAM_RESET, GPIO_CAM_XCLK, GPIO_CAM_SIOD, GPIO_CAM_SIOC, 
      GPIO_CAM_Y2, GPIO_CAM_Y3, GPIO_CAM_Y4, GPIO_CAM_Y5, GPIO_CAM_Y6, GPIO_CAM_Y7, GPIO_CAM_Y8, GPIO_CAM_Y9,   
      GPIO_CAM_VSYNC, GPIO_CAM_HREF, GPIO_CAM_PCLK
  }, 
  {
      PIXFORMAT_JPEG, FRAMESIZE_QVGA, 12, 2, 20000000,
  },
  camera_comp
});



//----------------------------------------------------------------------------------
// FONCTIONS LOCALES
String make_device_id(){
  uint64_t chip_id = ESP.getEfuseMac();
  char buf[17];
  snprintf(buf, sizeof(buf), "%012llX", (unsigned long long)chip_id);
  return (String(DEVICE_ID_PREFIX) + String(buf));
}



//----------------------------------------------------------------------------------
// SETUP
void setup() {
  Serial.begin(115200);
  Serial.println("\n[MAIN] Boot...");
  delay(8000);
  String device_id = make_device_id();


  //--------
  //--INIT--
  Serial.println("[MAIN] [MOT] motors controller init");
  if(motor_ctrl.init()) Serial.println("[MAIN] [MOT] -> init successful");
  else Serial.println("[MAIN] [MOT] -> init failed");
  Serial.println("[MAIN] [BAT] battery monitor init");
  if(battery_ctrl.init()) Serial.println("[MAIN] [BAT] -> init successful");
  else Serial.println("[MAIN] [BAT] -> init failed");
  Serial.println("[MAIN] [CAM] camera controller init");
  if(camera_ctrl.init()) Serial.println("[MAIN] [CAM] -> init successful");
  else Serial.println("[MAIN] [CAM] -> init failed");

  Serial.println("[MAIN] [BLE] provisioner init");
  ble_prov.init(device_id);
  Serial.println("[MAIN] [WFI] provisioner init");
  wifi_prov.init(device_id);
  
  //--------
  //-- --
  battery_ctrl.read();
  ble_prov.start();
  ble_prov.set_battery_level(battery_ctrl.get_percent_value());
  Serial.printf("[MAIN] device_id = %s\n", device_id.c_str());
  Serial.printf("[MAIN] battery = %f / %f\n", battery_ctrl.get_volt_value(), battery_ctrl.get_percent_value());

  //--------
  //--CORE--
  Serial.println("[MAIN] core init and start");
  core_init(&ble_prov, &wifi_prov, &motor_ctrl, &battery_ctrl, &camera_ctrl);
  core_start();
}

//----------------------------------------------------------------------------------
// LOOP (vide)
void loop() {
  vTaskDelay(pdMS_TO_TICKS(1000));
}

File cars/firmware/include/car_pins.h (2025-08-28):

#ifndef CAR_PINS_H
#define CAR_PINS_H



//----------------------------------------------------------------------------------
// DEFINES (PINS)
//----------------------------------------------------------------------------------
// DRIVER MOTEURS
#define     GPIO_MOT_A_DIR           3   // AIN1
#define     GPIO_MOT_A_DIR_PWM       4   // AIN2 (PWM)
#define     GPIO_MOT_B_DIR           1   // BIN1
#define     GPIO_MOT_B_DIR_PWM       2   // BIN2 (PWM)
#define     GPIO_MOT_SLP             44  // SLP (enable)
// MODULE ACCELEROMETRE
#define     GPIO_ACC_SDA             5
#define     GPIO_ACC_SCL             6
// MESURE BATTERY
#define     GPIO_BAT_SENSE           7
// CAMERA
#define     GPIO_CAM_PWDN           -1   // Pas de power-down hardware
#define     GPIO_CAM_RESET          -1   // Pas de reset hardware
#define     GPIO_CAM_XCLK           10   // Horloge XCLK
#define     GPIO_CAM_SIOD           40   // SDA (I2C du capteur)
#define     GPIO_CAM_SIOC           39   // SCL (I2C du capteur)
#define     GPIO_CAM_Y9             48
#define     GPIO_CAM_Y8             11
#define     GPIO_CAM_Y7             12
#define     GPIO_CAM_Y6             14
#define     GPIO_CAM_Y5             16
#define     GPIO_CAM_Y4             18
#define     GPIO_CAM_Y3             17
#define     GPIO_CAM_Y2             15
#define     GPIO_CAM_VSYNC          38
#define     GPIO_CAM_HREF           47
#define     GPIO_CAM_PCLK           13



#endif //CAR_PINS_H

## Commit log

2025-07-18 add landingPage folder
2025-07-23 Added first version of landing page
2025-07-24 deploy landing page
2025-07-28 bom + design
    [bom.xlsx]
2025-07-28 structure + add doc open source
    [bom.xlsx, xiao_esp32s3_sense_dimension_bot.dxf, xiao_esp32s3_sense_dimension_top.dxf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]
2025-07-28 diagram and bom is ok !
    [car.kicad_pcb, car.kicad_sch]
2025-07-28 add kicad projet for diagram + bom
    [car.kicad_pcb, car.kicad_sch]
2025-08-08 Added camera feed service
2025-08-13 Working on PC but needs to test on Raspberry with cars
2025-08-13 Add setup guide for Raspberry Pi Wi-Fi hotspot configuration
2025-08-15 Changed project reference chain
2025-08-18 first prototype of BLE worked
2025-08-18 first version of BLE workded
    [MAIN] Boot...
    [MAIN] BLE provisioner initialisé!
    [MAIN] BLE provisioner en attente de connexion...
    [MAIN] Connexion BLE établie
    [MAIN] Identifiants reçus → SSID: 'mon_wifi' | PASS: 'mon_motdepasse'
    [MAIN] Connexion BLE perdue
2025-08-18 first prototype of WiFi worked
    wifi credentials from ble
2025-08-19 add task connect and monitor all is oke
    [MAIN] [BLE] provisioner init
    [MAIN] [WIFI] provisioner init
    [MAIN] device_id = RL-CAR-d8:3b:da:73:b7:65
    [CONN] attente connexion BLE…
    [MON] actif (surveillance)...
    [MON] perte détectée: BLE=0 WIFI=0
    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
2025-08-21 Added test case for protocol
2025-08-21 add driver motor and battery sensor class
    but not tested
2025-08-22 add eFuze adc calibration
    Test is ok
2025-08-22 new id maker (chip id) + battery ble reader + task harware
2025-08-22 set uuid for all of motor direction
    Test reception is ok
2025-08-25 first version of motor drive
    Not tested, i will
2025-08-25 add ble value limits to protect motors
2025-08-25 fix calcul and test ok
    BEFORE--
    Battery : 4.09 / y : -1.00 / x : 0.00 / s : 0.73
    d : Backward / ls : 0.73 / rs : 0.73
    -> Sense ok
    -> max_speed : 4.09*0.73 = 2,98V ok
    -> ls=lr = 0.73 car 2,98v ok !
    Battery : 4.09 / y : 1.00 / x : 0.50 / s : 0.73
    d : Forward / ls : 0.37 / rs : 1.10
    -> Sense ok
    -> max_speed : 4.09*0.73 = 2,98V ok
    -> ls 4.09*0.37 = 1,51v
    -> rs 4.09*0.1 = 4,499v ko
    --> rs = 0.73 * ( 1 + 0,5 ) = ~1.1
    ----------------------------
    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
2025-08-26 ble route to set decay mode + fixe motor controller class + test ok
    Battery : 3.70 / y : 1.00 / x : 1.00 / s : 0.81 / dm : 0
    d : forward /dm : fast
    -> ls : 0.81 - ld : 206 / rs : 0.00 - rd : 0
    -> speed -> 3.7*0.81 = 2.997v ok
    - ls -> 3.7*0.81 = 2.997v et 3.3*0.81 = 2,673 (BIN1=2,646v) ok
    - rs -> 3.7*0.0 = 0v et 3.3*0.0 = 2,0 (AIN1=0v) ok
    - BIN2 = AIN2 = 0
    ---
    Battery : 3.70 / y : 1.00 / x : 0.00 / s : 0.81 / dm : 0
    d : forward /dm : fast
    -> ls : 0.81 - ld : 206 / rs : 0.81 - rd : 206
    -> speed -> 3.7*0.81 = 2.997v ok
    - ls -> 3.7*0.81 = 2.997v et 3.3*0.81 = 2,673 (BIN1=2,646v) ok
    - rs -> 3.7*0.81 = 2.997v et 3.3*0.81 = 2,673 (AIN1=2,646v) ok
    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
2025-08-26 maj of bom
    [bom.xlsx]
2025-08-26 now also working on the raspberry but needs an bluetooth dongle
2025-08-27 add thread-safe to ble comm
2025-08-27 class camera + init + task vid tested
    [MAIN] [BAT] battery monitor init
    [MAIN] [CAM] camera controller init
    [MAIN] [CAM] -> init successful
    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
2025-08-27 uniforme battery class name
2025-08-27 refacto thread management
    not tested
2025-08-27 smal fixe + test ok !
    [MAIN] [MOT] motors controller init
    [MAIN] [MOT] -> init successful
    [MAIN] [BAT] -> init successful
    [MAIN] [WFI] provisioner init
    [MAIN] device_id = RL-CAR-08910D97BACC
    [MAIN] battery = 4.010250 / 78.916695
    [MAIN] core init and start
    [TASK_CON] START
    [TASK_CON] setup: états nettoyés
    [TASK_CON] attente BLE…
    [TASK_CON] BLE : connecté
    [TASK_CON] attente credentials…
    [TASK_CON] credentials : SSID='yallo_6317357' PASS='gzz4pWb5Vpmrjzox'
    [TASK_CON] attente Wi-Fi…
    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
2025-08-28 new chassis with new motor + add all of step files
    [adafruit_drv8833.step, car_base.stl, car_chassis.stl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]
2025-08-30 Added refresh button and small changes
